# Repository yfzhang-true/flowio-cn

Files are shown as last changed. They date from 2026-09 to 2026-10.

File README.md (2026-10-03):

# FLOWIO-CN

**Open-source pneumatic soft robotics control platform** — from 4-layer PCB to digital twin.






## What is this?

FLOWIO-CN is a fully open-source, production-ready pneumatic soft robotics control platform. It's the Chinese domestic alternative to MIT's FlowIO, designed for B2B rehabilitation glove manufacturers (¥300-500/kit including board + firmware + SDK).

**One person, AI-driven, from zero to product in 3 days.**

## Architecture

```
┌─────────────────────────────────────────────────┐
│  Digital Twin (Web)                             │
│  3D exploded view · airflow/current viz        │
│  Real-time telemetry · simulation lab          │
├─────────────────────────────────────────────────┤
│  Python SDK · BLE GATT · Serial CLI            │
├─────────────────────────────────────────────────┤
│  ESP32-S3 Firmware (ESP-IDF + FreeRTOS)       │
│  pn_core (platform-independent C)              │
│  TCA9548A I2C mux · WS2812 · 8× valve PWM    │
├─────────────────────────────────────────────────┤
│  4-Layer PCB (90×75mm) · FreeCAD enclosure    │
│  JLC fab-ready · via-in-pad Type VII          │
└─────────────────────────────────────────────────┘
```

## Quick Start

### Digital Twin (no hardware needed)
```bash
cd firmware/twin
"E:/Program Files/KiCad/10.0/bin/python.exe" server.py
# Open http://localhost:8000
```

### Flash Firmware
```bash
cd firmware
idf.py flash monitor
```

### Python SDK
```python
from flowio_sdk import FlowIO
device = FlowIO("COM3")
device.inflate(port=1, pwm=180)
device.hold(port=1)
```

## Repository Structure

| Directory | Description |
|---|---|
| `firmware/` | ESP32-S3 firmware + digital twin + tests |
| `hardware/flowio-p1/` | KiCad PCB project + fab package |
| `sdk/python/` | flowio_sdk Python package |
| `book/` | LaTeX book source (94 pages, Chinese) |
| `docs/superpowers/` | Engineering specs & plans |
| `enclosure/` | FreeCAD parametric case |

## Key Metrics

| Metric | Value |
|---|---|
| PCB layers | 4 (F: signal · In1: GND · In2: power split · B: signal) |
| DRC violations | **0** (from 146 initial) |
| Host tests | 33/33 ✅ |
| Web app tests | 44/44 ✅ |
| API tests | 50/50 ✅ |
| BLE services | 4 (Command · Telemetry · Config · DeviceInfo) |
| Book | 94 pages · 14 chapters · 31 bib entries |

## Documentation

- [BRINGUP Guide](firmware/BRINGUP.md) — Hardware bring-up checklist
- [API v1.2](firmware/twin/API.md) — HTTP interface spec
- [BLE Interface](firmware/twin/BLE.md) — GATT service/characteristic spec
- [Book PDF](book/build/main.pdf) — 《气动软体机器人自研实战》(in progress)

## License

- **Code**: MIT License
- **Hardware (PCB/enclosure)**: CERN-OHL-S v2
- **Documentation/Book**: CC BY-NC-ND 4.0

## Author

**张越飞 (Zhang Yuefei)** — Embedded Software Engineer
- GitHub: [@yfzhang-true](https://github.com/yfzhang-true)
- Email: yuefeizzz@163.com

---

*Built with AI-driven development methodology. Every spec, plan, test, and commit is documented in `docs/superpowers/`.*

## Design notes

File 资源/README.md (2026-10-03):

# E:/FLOWIO/资源 — 分类清单（2026-10-03 整理后 627M→401M）

## 实物图/（59 图）
- handes_p1-p18: 汉戴斯 FlowIO 代工平替 PCB 实物 → 书稿 ch5 供应链
- valve0520d_*/0520f_*: 两种阀实拍 → ch2 阀选型对照
- mos_p1-p7 / sanjian_p1-p9 / xgzp_p3 / dmm / solder_check → ch5/ch13
- 1-4.png / BOM*.png: 其他采购截图

## 器件规格书/（7 项+2 目录）
- 电磁阀 0520D/F 中文规格书（P_min=-53.3kPa 来源）→ ch2 bib
- XGZP6897D V1.1 + 数据手册/（含 V2.5/ESP32-WROOM 中文/TCA TI 版）→ ch2/ch7 bib
- AO3400A/电感/DC005/XH/CH340N（数据手册/ 目录）→ ch3 bib

## 官方参考/（17 项 + official-3mf/22 模型）
- FlowIO CHI'21 论文 PDF + Arduino 库 7 源文件 + mp4 + gui.html（对标素材，版权纪律：只引签名不摘码）
- official-3mf/: S/M/L/Main 模块结构件 → ch6 尺寸对照表

## 开发板资料/（4 项）
- DevKitC-1 原理图 PDF + N16R8 资料目录 + Arduino API 文档 + AeonLabs 工程 → ch3 对照

## 已删（226M）
- FLOWIO-外部参考（嵌套残留）/ extracted/(116M) / kicad/(32M) / kicad zip(53M) / TCA rar(25M)

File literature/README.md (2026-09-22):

# 文献库总台账

> 命名规范：`YYYY-一作姓[-venue]-slug.pdf`（经内容验证后统一重命名，2026-09-22）
> 结构：根目录 = 15 篇精读核心；`citers/` = 81 篇 FlowIO 被引（S2 元数据对账）
> 全部 PDF 配同名 `.txt` 提取文本（图片扫描件除外）；原始数据 `s2_*.json`

## 一、核心文献（根目录，14 篇，全部深读）

### 平台与物理（FlowIO 复刻主线）

| 文件 | 文献 | 价值 |
|---|---|---|
| `2021-shtarbanov-chi-ea-flowio.pdf` | FlowIO 平台（CHI'21 EA，被引 101） | 对标本体：7 常闭阀架构、单传感器分时、±179/+207kPa 包线、泵 PWM 调流 |
| `2025-shtarbanov-phd-thesis.pdf` | Shtarbanov 博士论文（303 页） | **Table 2/3 泵实测锚点**（Small -38~+61kPa/±0.3L/min）、5 配置、12 部署案例、模块生态 |
| `2022-xavier-frontiers-nonlinear-controllers.pdf` | Xavier 控制器论文（Front. Robot. AI） | 物理模型权威：dP/dt=γP/V·Q + ANSI 阀孔方程 + choked、γ=1.2 |
| `2020-xavier-aim-pneumatic-sources.pdf` | Xavier 泵源建模（IEEE/ASME AIM 2020） | 正排量泵=理想流量源；储气罐平滑；FCB 综述 |
| `2020-stanley-asme-lumped-param-circuits.pdf` | Stanley & Amini RC 时序（ASME） | 次要损失阻力 ΔP=½Kρu²；RC 动力学；验证区 0.5–16mL 互洽 |
| `2013-yao-uist-pneui.pdf` | PneUI（UIST'13，被引 201-1000） | 界面设计参考：压力→形变连续映射、各向异性材料 |
| `2021-afsar-uist-omnifiber.pdf` | OmniFiber（UIST'21） | 流体纤维驱动、绕线交互（Shtarbanov 合作） |
| `2022-youn-tei-pneubots.pdf` | PneuBots（TEI'22） | 模块化充气教育套件——P0 教育定位直接对标 |
| `2022-aljomairi-smarchs-thesis-pneuknit.pdf` | PneuKnit（MIT SMArchS 2022） | 气压针织自成形（建筑/可穿戴） |

### 精细动作控制（2026-09-22 新增，笔记 19/20/21）

| 文件 | 文献 | 价值 |
|---|---|---|
| `2026-chen-arxiv-cnc-ergonomic-glove.pdf` | Chen 2026（arXiv 2604.00768，Sant'Anna） | **架构同构验证**：ESP32 WiFi+浏览器 GUI+12 电磁阀+双作用+CNC 热封（FDM 改装）+90g；患者 50-70kPa |
| `2026-xie-advsci-portable-thumb-glove.pdf` | Xie 2026（Advanced Science，CUHK 汤启宇组，CC-BY，DOI 10.1002/advs.76275） | **拇指精细答案**：双腔折纸差压（143°）、18N、XGZP6857A 传感器（同我们 BOM）、IMU 测角、贝叶斯 AAN 控制 |
| `2026-yilmaz-amt-fabric-gloves-review.pdf` | Yilmaz 2026 综述（Adv. Mater. Technol.，CC-BY，DOI 10.1002/admt.202502282） | **行业地图**：5 大制造家族；"开环对康复手套根本不够"；行业无统一测试标准=评估卖点机会 |
| `2026-xu-uppsala-pneumatic-circuits-thesis.pdf` | Xu 2026 博士论文（Uppsala） | 无电子气动逻辑+多路复用（技术雷达）；RC 类比验证一阶充放气建模 |
| `2022-wang-appsci-thumb-assist-comparison.pdf` | Wang 2022（Applied Sciences 12:3735，千叶大学，CC-BY） | **拇指通道裁决**：3C-ACT 三腔独立 Kapandji 满分 vs M-ACT 模块化耦合 0-5；最优组合=3C 拇指+模块四指；"控制方法待开发"=B2B 定位原文 |
| `2018-cn108392375a-patent-pneumatic-glove.pdf` | 专利 CN108392375A（郑州大学） | 免费竞品拆机（图片扫描件，无 txt；全文拆解见笔记 20）：双泵/双作用/12 传感/迭代学习 |
| `2022-sansone-actuators-sma-torsion.pdf` | Sansone 2022（Actuators 11:81） | ⚠️ 误下载（想要 3C-ACT 拇指论文，此为 SMA 扭转执行器）；留档，与产品无关 |

## 二、被引文献（citers/，81 篇）

- 完整索引（标题/一作/venue/被引/本地文件）：**[citers/INDEX.md](citers/INDEX.md)**
- 阅读笔记（分层：深读/扫读）：**[citers/READING-NOTES.md](citers/READING-NOTES.md)**
- 学术地图与客户清单：**[../study-notes/14-学术地图与潜在客户.md](../study-notes/14-学术地图与潜在客户.md)**

## 三、检索与整理方法存档

- AMiner：精确标题走 `search_paper_by_title`（keyword-only 常返回 no data）；被引清单用 S2 API；机构信息 `get_paper_detail`
- DOI 勘误：Xavier 2022 = 10.3389/frobt.2022.**818187**；FlowIO 系 CHI'21 EA；Yilmaz 综述 = **10.1002/admt.202502282**（Advanced Materials Technologies，非 Advanced Science）；Wang 拇指对比 = **10.3390/app12083735**（Applied Sciences 12(8):3735，非 Actuators）
- 下载坑：远端静默截断（无 %%EOF）需续传重下；ACM/Wiley/MDPI 反爬交用户浏览器（Cloudflare 拦 curl/WebFetch）；Google Patents PDF 是图片扫描件（无 txt，内容走网页版）
- 验证流程（2026-09-22 定型）：pypdf 页数+首页文本 → 标题/作者/DOI 比对清单 → 统一命名 `YYYY-一作姓-venue-slug` → 全文 .txt 提取（errors='replace'）→ 误下载留档并注明
- 本机 Python：`D:\MiniConda\python.exe`（PATH 里 `WindowsApps/python` 是商店占位符 exit 49，`/d/miniconda3` 不存在）
- 重命名流程：pypdf 提取首页 → 归一化标题前缀匹配 S2 元数据（75/82 自动）→ DOI/人工补 6 篇 → 重复件（Xavier controllers citers 副本）删除

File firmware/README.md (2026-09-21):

# FlowIO 兼容 P0 固件（ESP32-S3）

对标 FlowIO 功能的自主实现固件（100% 原创代码，逻辑依据 study-notes/02 功能性笔记）。

## 目录结构

```
components/
  pn_core/       纯逻辑层（动作/闭环/协议）——不依赖任何平台，主机可测
  pn_hal_esp32/  ESP32-S3 硬件层（LEDC 阀/泵 + RMT 舵机 + I2C 传感器）
main/            app_main：10ms 控制任务 + 串口 CLI
tests/           主机单元测试（gcc/cmake/ninja，无需 ESP-IDF）
```

## 分层架构

```
应用层   main.c（CLI + 10ms 控制任务）
协议层   proto.c  [0xA5][cmd][ports][pwm][crc8]
动作层   actions.c / closedloop.c（端口三胞胎/方向阀/泵/状态字/节能/超压保护/压力闭环）
HAL      hal_if.h 契约 ← pn_hal_esp32 实现（目标机）/ mock_hal（测试）
```

## 主机单元测试（改逻辑必跑）

```bash
cd tests
cmake -B build-test -G Ninja -DCMAKE_BUILD_TYPE=Debug
cmake --build build-test
./build-test/pn_tests.exe        # 21 tests 全绿 = 逻辑层可信
```

## 目标机构建/烧录（需 ESP-IDF v5.5.5 @ E:\Espressif）

```bash
./idf_build.sh build     # 编译（生成 build/flowio_p0.bin，目标 esp32s3）
./idf_build.sh flash     # 烧录（接开发板 USB 口）
./idf_build.sh monitor   # 串口监视器（Ctrl+] 退出）
```

## 串口 CLI（115200）

| 命令 | 功能 | 示例 |
| --- | --- | --- |
| `I <ports> <pwm>` | 充气 | `I 1 255` |
| `V <ports> <pwm>` | 抽气 | `V 1 200` |
| `R <ports>` | 释放 | `R 1` |
| `S <ports>` | 停止/保压 | `S 1` |
| `O <ports>` / `C <ports>` | 开/关端口阀 | `O 7` |
| `P` | 读传感器（kPa） | |
| `T` | 打印状态字 | |
| `L` | 阀保持节能 | |

## 状态字位定义

bit0-4=端口1-5 开、bit5=进气阀、bit6=排气阀、bit7=泵、bit9=传感器在线、bit15=错误。
协议层预留设备 ID 字段位（多设备同步，对标 FlowIO JS API 多机协同）。

## 安全设计

- 上电默认全关（常闭阀 + duty=0）；
- 超压保护为**硬规则**（pn_check_overpressure），任何上层不可关闭；
- TinyML/智能层永远是并行观察者，不进控制路径（study-notes/11）。

## 虚拟设备（无硬件调试）

逻辑层 + mock HAL 跑在电脑上，命令与真机完全一致：

```bash
cd virtual
cmake -B build -G Ninja && cmake --build build
./build/pn_virtual.exe
```

虚拟专属命令：`M <传感器号> <kPa>`（模拟压力读数）、`W <ms>`（推进时钟）、`K`（手动闭环 tick）、`Q` 退出。
示例：`I 1 255` → `M 0 30` → `G 1 40 0` → `K`（RUNNING）→ `M 0 45` → `K`（DONE reached=45kPa）→ `S 1`。

## 型号说明书

E:\FLOWIO\资源\datasheets\：ESP32-S3-WROOM-1 中文数据手册、XGZP6897D V2.5、TCA9548A。
DevKitC-1 用户指南（在线）：https://docs.espressif.com/projects/esp-idf/zh_CN/latest/esp32s3/hw-reference/esp32s3/user-guide-devkitc-1.html

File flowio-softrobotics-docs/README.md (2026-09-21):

# FlowIO（软体机器人气动平台）本地文档

FlowIO = Ali Shtarbanov（MIT Media Lab）开发的软体机器人气动开发平台，
官方文档站 <https://www.softrobotics.io/>（Wix 站点，2026-09-19 抓取转换为 Markdown）。

| 本地文件 | 内容 |
| --- | --- |
| `introduction.md` | Introduction |
| `documentation.md` | Documentation Overview |
| `gui-overview.md` | GUI Overview |
| `gui.md` | Launch GUI |
| `auto-off.md` | Auto Power OFF |
| `battery-charging.md` | Battery Charging |
| `pneumatic-configurations.md` | Pneumatic Configurations |
| `external-air-supply.md` | External Air Supply |
| `latency-and-delays.md` | Latency & Delays |
| `more-than-5-ports.md` | More Than 5 Ports |
| `software-stack.md` | Software Stack |
| `arduino-api.md` | Arduino API |
| `premium-content.md` | Premium / IoT Features |
| `limitations.md` | Limitations |
| `about.md` | About |
| `chi22.md` | CHI'22 Paper Page |
| `dis23.md` | DIS'23 Paper Page |
| `fab24.md` | FAB24 Paper Page |

补充材料：
- `arduino-library-readmes/` — GitHub 上 FlowIO Arduino 库的 README（API 文档入口，固件等高层代码在私有仓库需申请）
- `images/` — 页面配图（含气动配置、GUI 截图等）
- 论文：`E:\FLOWIO\FlowIO Development Platform – the Pneumatic "Raspberry Pi"for Sof Robotics.pdf`（CHI 2021，与官网首页挂载的 PDF 为同一文件）
- Arduino 库源码：`E:\FLOWIO\FlowIO-Arduino-Libraries-master\`（github.com/shtarbanov/FlowIO-Arduino-Libraries，
  含 `FlowIO_Library_2026.03.23` 最新版库 + 236 个示例 `.ino` + 历史版本；另保留同名 .zip）
- free/pro 版库仓库（shtarbanov/FlowIO-Library-free-version- / -pro-version-）为空占位，需向作者申请私有固件仓库访问

未抓取（非文档内容）：商店/社区论坛/法律条款等页面。

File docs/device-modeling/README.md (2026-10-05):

# D4 视觉回归存证 — 孪生 3D 器件精确建模 + connections 驱动渲染 (2026-10-05)

> spec: docs/superpowers/specs/2026-10-05-device-modeling-connections-design.md §5/§7(验收 4)
> 截图: 本目录 `d4-*.png` (1680×1050, playwright 无头; 脚本 `firmware/twin/shots_d4.js`,
> 需 8017 孪生服务: `bash firmware/twin/run_tests.sh` 或手动起 `server.py`)。
> 重生成: `cd firmware/twin && node shots_d4.js [输出目录]` (默认落本目录)。

## 截图清单与判定点

| 截图 | 视角/态 | 判定点 (spec E1/E2 校正) |
|---|---|---|
| `d4-pump-top.png` | 泵模块装配位 + **隐壳透视** (截图工具临时 `pump_case.visible=false`, 非场景功能; 泵在封闭腔内, 唯一诚实观查法) | **顶置双嘴 ⌀4.2 垂直于泵轴** (E1: 旧版误建侧嘴); 泵头⌀24/电机⌀27 两段式; 硅胶支架环×2 抱头段/电机段; 电机端面红黑引线; 模块内跳管 (fit_pending 半透明) 自双嘴下行至面板快插 |
| `d4-valve-leads.png` | B 壁 (+Y) 正视塔层 | 11 阀 C 架本体 (devices3d 精确模型, 非盒近似); **红黑引线自阀 -Y 侧出体 → 拱越 (z43.5, 阀顶与歧管块底净空带) → 沿壳外壁下落 → 穿 B 壁 TERM 槽 → 2P 白壳插入 J10-J17** (E2: 旧版引线缺失); 白壳视觉件在插座位; 测压支路自歧管顶过天花过孔垂直下行 |
| `d4-tube-routing.png` | 全局 3/4 (装配态) | **connections.json 驱动管路** (16 管, D4-A 折线): 模块间干管×2 (面板快插→R 壁 S/V 孔), 壳内 S/V/F 竖落管, 通道管 V×N2→CH 过孔, 测压支路 (歧管测压嘴→越歧管顶→天花过孔→XGZP P1); 泵电缆 J23→R 壁槽→模块出线孔→电机端子 |
| `d4-explode-follow.png` | 爆炸 k=1 | 连接边**端点随部件跟随拉伸** (spec §5): 测压支路自歧管层拉至 pcb 层, 模块干管拉伸跨主/泵模块间隙 —— 分装式教学价值可视 |
| `d4-click-highlight.png` | 点击 J10 热点 (raycaster 真点击) | 三类连接**高亮分色** (电气琥珀, 其余压暗); 提示 chip (左下): 器件名 + 气动/电气/机械计数; 热点卡照常弹出 (webapp 组件契约不破, 现 55/55) |

## 与官方参考照/实物照对照

参考照在主仓库 (worktree 外, 绝对路径):

| 孪生截图 | 参照 | 对照结论 |
|---|---|---|
| d4-pump-top.png | `E:/FLOWIO/literature/ZR370-03PM.pdf` p2 图纸 (顶置 2-⌀4.2 出气/进气口标注) + `E:/FLOWIO/资源/实物图/1.png`-`4.png` (整机实物) | 嘴位/朝向/头-电机两段比例一致; 充(S)/吸(V) 固定不可反接 (图纸标注同) |
| d4-valve-leads.png | `E:/FLOWIO/literature/F0520D.pdf` p2 图纸 + 实物照 `E:/FLOWIO/literature/extract/散件/` (p0-p8, 红黑引线+2P 白壳) + `E:/FLOWIO/资源/实物图/电磁阀052/` | C 架比例 (20.5×15×13 + 翻边)、红黑并排引线、白壳插接方向一致; F0520B/VV 总长 28+⌀4.6 顶嘴承插悬置态 (图纸直推) |
| d4-tube-routing.png | `E:/FLOWIO/资源/官方参考/flowio-official-gui-reference.png` (官方 GUI 整机) + `docs/pneumatic-diagram.md` §1-§5 (图谱拓扑真值) | 管路拓扑按 connections.json (机器真值) 而非目测; 官方为集成式单壳, 本机为分装双模块 (1h 决策), 干管跨接为设计意图非偏差 |
| d4-click-highlight.png | — (交互新增, 无官方对应) | spec §5 "点击器件→高亮其三类连接" 落地存证 |

## 已知视觉限制 (诚实记录, 非缺陷遮掩)

1. **引线/管与结构件的过越穿模**: 壳盖 (case_top) 无阀 N2 过孔/引线过孔 (盖开孔属
   enclosure 域待 1a 支架定型), 渲染折线穿过盖板处阅读为"过孔"; VS/VF 竖落管与
   J20/J22 插座体量轻微交叠 (真实走线在插座旁, 折线未让位)。
2. **tube.bend=2 为采购下料名义值**, 渲染折线按最小几何弯折 (2~4 点, 壁孔过越/障碍
   让位必须) —— 段长和仍可核算下料 (D4-A), 逐边路径见
   `firmware/twin/webapp/connections_scene.json` (flowio/twin/connections_render 生成)。
3. **引线桩深** = D2-A "诚实的不精确" (~60mm 视觉桩语义, 端点接真值插座位);
   精确线长/壳内走线属机械冻结后阶段 (spec §8 D2)。
4. V2-V8 N2→CH 的 **x 向让位折线** 按 connections.json 字面映射渲染 (V2→CH2@29.5 等
   与阀列 x 不对齐处出现横行段) —— 配对疑点已核闭 (原 D4 报告"数据发现"收编于此):
   交织序下 V5.N2 (后行阀列 x=20) 映射 CH5@x=58, 渲染横行段横跨 38mm 为最长者;
   与 `connections.json _meta.conventions.vi_ch_pairing` 约定自洽 —— Vi→CH{i} 恒等
   配对是图谱拓扑约定, CH 孔-阀前后行的物理对号未钉真值 (case_geom CH_PORT_X 每列
   2 孔对应该列前/后行阀), 四条校验不受配对影响; BRINGUP §C 接管时对号, 本疑点关闭。

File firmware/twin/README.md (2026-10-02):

# twin/ — FlowIO-CN 数字孪生 + Web 控制台

启动：

```bash
"E:/Program Files/KiCad/10.0/bin/python.exe" server.py   # KPY（KiCad 自带 Python）
# → http://127.0.0.1:8000/
```

P1 板级说明：本目录含 P1 板级电气孪生（board_model）/参数化仿真（sim_engine）/3D 装配（meshes），
协议契约见 `API.md`（v1.2）与 `BLE.md`（真机 Web-Bluetooth 模式）；回板校准动线见 `firmware/BRINGUP.md`。

## 前端 v2（webapp/，2026-10-02 交付）

`/` = v2 产品爆炸视图核心（零构建 ES Modules，`webapp/` 直服）：

- **全屏 3D 产品场景**为唯一主角：装配叙事（加载 1.5s 部件散位收敛）+ 运输条爆炸滑杆（0-100%），
  材质对标 Liquid Glass（壳喷砂灰 / PCB 墨绿微金属 / 器件中性灰 + 环境反射）。
- **气流粒子与电流辉光长在产品上**：流拓扑由 `hardware/flowio-p1/enclosure/make_flows.py`
  从 pos.csv 同源生成 `webapp/flows.json`/`hotspots.json`；电流=行进虚线（阀电流驱动 uGain/uSpeed），
  气流=端口 Bezier 粒子流（duty 驱动速度，真空=琥珀色反向）。
- **仪表盘降级为辅助**：左控制抽屉（阀/泵 Apple 分段控件 → CLI）/ 右遥测抽屉（5 张 sparkline 玻璃卡，
  点卡展开 ECharts）/ 器件热点卡（点击 3D 器件）/ 仿真实验室全屏浮层 / 状态行（stale 红点/未标定黄徽）。
- `?debug` 叠 fps/粒子/延迟浮层；真机模式=顶栏「连接真机」（Web Bluetooth，0xA5 帧，`ble.js`）。
- 调试钩：`window.__t2 = {scene, flows, panels, simlab}`（test_webapp.js 全链断言经此读取渲染态）。
- 旧版 gui.html 挂 `/classic` 过渡（`/gui` 301→`/`）；API v1.2 端点零改动。

截图（`shots/v2_*.png`）：`v2_01_intro` 首屏装配 · `v2_02_explode50` 爆炸 50% ·
`v2_03_inflate`/`v2_04_silent` 充气/静默差分 · `v2_05_vacuum` 真空琥珀反向 ·
`v2_06_hotspot` U3 热点卡 · `v2_07_telemetry` 遥测抽屉 · `v2_08_simlab` 仿真浮层 ·
`v2_09_stale` 断连态 · `v2_10_recovered` 恢复态。

测试：`node test_webapp.js`（v2 全链 44 断言，需 8017 实例）+ 旧三套（test_gui/test_gui_p1/test_e2e 已挂 /classic）。

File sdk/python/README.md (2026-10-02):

# flowio_sdk — FLOWIO-CN 上位机 Python SDK

0xA5 二进制帧协议的 Python 实现，编解码与固件 `firmware/components/pn_core/src/proto.c` **同向量**（测试向量共享，见 `tests/vectors.json`）。

```bash
pip install pyserial                      # 可选依赖（仅串口传输需要；SDK 本体 stdlib-only）
python examples/hello_glove.py COM3       # 充→保→释→抽 一个来回
```

```python
from flowio_sdk import FlowIO
io = FlowIO("COM3")          # 或 FlowIO(transport=自备对象) 离线测试
io.inflate(1, 180)           # '+' 端口1 充气 180/255
io.hold(1); io.release(1)    # '!' 保压 / '^' 释放
print(io.state())            # 'S' 读状态字（str）
```

协议真源与帧格式：`firmware/components/pn_core/include/pn_core/proto.h` —— 5 字节帧 `[0xA5][cmd][ports][pwm][crc8]`，cmd 为 ASCII 动作码（`! + - ^ o c ? S R`），ports 为 bit0..4 端口掩码，CRC-8 poly=0x07 init=0x00 覆盖前 4 字节。

测试：`python tests/test_protocol.py`（8 组固件同向量双向校验，通过输出 `sdk protocol tests OK`）。

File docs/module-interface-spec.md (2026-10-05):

# FLOWIO-CN 模块接口规约（Module Interface Spec · device-modeling D3）

> **机器真值源**：`hardware/flowio-p1/enclosure/connections.json`（modules 块 + 三类边——面名/
> 计数/口径/管长/边数全部摘自它）· `hardware/flowio-p1/enclosure/devices.json`
> `pneumatic_devices.*.geom3d`（端点级位/向/径细节）。
> 本文档是连接图谱的**人读投影**：数据分歧以 connections.json 为准；守卫测试
> `flowio/tests/test_module_interface_spec.py` 把本文硬编码数字钉在真值上（漂移必红）。
> 上游：spec `docs/superpowers/specs/2026-10-05-device-modeling-connections-design.md` §1/§4 ·
> 气路真值 `docs/pneumatic-diagram.md` §3 · 装配执行 `docs/bringup-checklist.md`。
> 生成日期：2026-10-05（D3）。架构：1f-β 公共歧管 + 1h 分装式双模块，全 NC 阀。

## 1. 总则

1. **接口先于几何**：每器件 = 三接口面（气动/电气/机械）+ 参数化几何；几何服务于接口。
2. **模块 = 器件 + 内部边组合**：主模块 = 主板/歧管/11 阀/壳内管路的组合，泵模块 = 泵 +
   面板快插 + 底座 + 跳管的组合；内部边两端点均在本模块内，不承担模块间契约。
3. **对外接口面 = 模块间边的端点**：模块间恰 3 条边（2 气管 + 1 电缆），其端点即两模块的
   全部对外契约；其余面对内（壳内免维护）。
4. **一致性声明**：本文所有面名/口径/长度/边数可溯源到 connections.json（modules 块与三类
   边）与 devices.json geom3d；手改真值后本文由守卫测试逼同步，**禁止在文档发明第二套接口数据**。

### 1.1 模块总览（数据来源：connections.json modules 块）

| 模块 | 功能 | 面（气动/电气/机械） | 面合计 | 对外面 | 物理形态 |
|---|---|---|---|---|---|
| Main | 控制与分配 | 12 / 12 / 4 | 28 | 12 | 主壳（R 壁 S/V/F 孔带 z=5.0 + B 壁 CH×8 @z=17.25） |
| PMod | 气源 | 2 / 1 / 1 | 4 | 4 | 独立小盒 66.9×32.8×41.3，主壳 +X 侧间距 30，桌面放置 |
| ATM | 大气环境节点（非实体） | 1 / 0 / 0 | 1 | 1 | 排气终端与传感表压基准的显式接地 |

边计数合计：气动 29 / 电气 14 / 机械 15（`flowio.twin.connections` 校验锚点，与
`test_connections.py` N_PNEU/N_ELEC/N_MECH 同源钉死；模块间边恰 3 条见 §4）。

### 1.2 对外接口面清单（数据来源：connections.json modules 块 external=true 面）

| 面地址 | 类 | 口径 | 用途/位置 |
|---|----|---|---|
| Main.S_wall | 气动 | ⌀5.6 | 充干管接入（R 壁 @y20.4 z5.0；S=充不可对调） |
| Main.V_wall | 气动 | ⌀5.6 | 吸干管接入（R 壁 @y31.4 z5.0） |
| Main.F_wall | 气动 | ⌀4.8 | 排气→大气（R 壁 @y42.4 z5.0，可塞消音棉，无密封要求） |
| Main.CH1 | 气动 | ⌀3.4 | 通道管→cuff（B 壁 @x20.0 z17.25） |
| Main.CH2 | 气动 | ⌀3.4 | 同上（@x29.5） |
| Main.CH3 | 气动 | ⌀3.4 | 同上（@x39.0） |
| Main.CH4 | 气动 | ⌀3.4 | 同上（@x48.5） |
| Main.CH5 | 气动 | ⌀3.4 | 同上（@x58.0） |
| Main.CH6 | 气动 | ⌀3.4 | 同上（@x67.5） |
| Main.CH7 | 气动 | ⌀3.4 | 同上（@x77.0） |
| Main.CH8 | 气动 | ⌀3.4 | 同上（@x86.5） |
| Main.J23 | 电气 | XH2.54-2P（C7429671） | 泵电机座（Q16；穿壁电缆→泵模块） |
| PMod.S_panel | 气动 | ⌀5.6 | 面板充气快插（泵出口侧） |
| PMod.V_panel | 气动 | ⌀5.6 | 面板吸气快插（泵入口侧） |
| PMod.cable_2p | 电气 | 2P 插头（出线孔 ⌀5.0） | 电机插头←主模块 J23 电缆 |
| PMod.base | 机械 | — | 自足式底座（桌面放置，无壳间紧固） |
| ATM.open | 气动 | — | 大气（表压 0 基准；F 排气与 XGZP P2 的接地目标） |

## 2. 主模块 Main（控制与分配）

**功能**：接收 USB-C 5V 单电源，驱动 11 路 NC 电磁阀（V1-V8 通道阀 + VS 充/VV 吸/VF 排三
主阀）构成 1f-β 公共歧管，把泵模块送来的气压分配/回收至 8 通道 cuff；板载 XGZP6897D 实时
测压闭环（>±35kPa 工作带、M>+35 停泵 `0x02`、M<−40 真空钳位 `0x04`，diagram §1）。壳内
气路/阀线免维护——模块间契约仅 §4 的 2 管 1 缆。

### 2.1 三接口面表（数据来源：connections.json modules 块 Main 条目）

| 面 | 对内 | 对外 |
|----|---|---|
| 气动（12 面） | M 公共歧管腔脊 ⌀4.0（内部枢纽：11 阀嘴承插 + 测压支路接入；内流道 ⌀3.2） | 11 壁面孔：S_wall/V_wall ⌀5.6（→泵模块）、F_wall ⌀4.8（→大气）、CH1-CH8 ⌀3.4（→cuff）。引压口无独立面，由 M→S1.P1 边承载（歧管测压嘴 ⌀4.4×伸出 5，右面 x=105） |
| 电气（12 面） | J10-J17（8 通道阀座）+ J20（VS）+ J21（VV）+ J22（VF）共 11 座 XH2.54-2P，板载阀驱动 | J23 泵电机座（XH2.54-2P，Q16 驱动）→穿壁电缆→泵模块。USB-C 电源输入（J1）属板级/网表域，不入图谱（conventions.elec_scope） |
| 机械（4 面） | valve_bracket 阀印刷支架 / manifold_seat 歧管 4 支腿 M3 座 / case_cover 壳盖承面 / pcb 主板板面 | —（壁面快插/出线孔按真值归气动/电气面；壳间无紧固） |

### 2.2 对内构成（数据来源：connections.json 三类边涉及 Main 端点条目统计）

| 域 | 边数 | 构成 |
|----|---|---|
| 气动 | 24 | 11 承插（V1-V8/VS/VF 嘴 ⌀3.0→承口 ⌀3.2；VV 嘴 ⌀4.6→承口 ⌀4.8+变径腔 z50 锥收，插入 ~5.5mm）+ 3 壳内主阀/排气管（S_wall→VS.N2、V_wall→VV.N2 各 ID5→ID3 200mm；VF.N2→F_wall ID3 200mm）+ 8 通道管（Vi.N2→CHi，ID3×OD7 175mm）+ 测压支路 M→S1.P1（ID3×OD7 500mm 死端引压）+ F_wall→ATM 排气终端 |
| 电气 | 11 | 阀引线 2P 白壳→XH 座（V1-V8→J10-J17、VS/VV/VF→J20/J21/J22），桩深 60mm（D2-A 视觉桩） |
| 机械 | 13 | 10×D 阀 C 架顶翻边固定（V1-V8/VS/VF）+ 1×VV B 阀 ⌀2.0 孔×2 螺固 + 1×XGZP SOIC8 板载回流焊 + 1×歧管 4 支腿 M3 立于壳盖 |

## 3. 泵模块 PMod（气源）

**功能**：自足式气源小盒——ZR370-03PM 泵（头 ⌀24×27.3 + 电机 ⌀27×30.8，总长 58.1 横躺，
**顶置双嘴 ⌀4.2×7.5 垂直于轴线**）+ 面板双快插 + 底座硅胶支架减振；哑器件，电机 2 线回主
模块 J23（Q16），占空比 ≤95% 调速，充/吸口由泵结构固定（电机反接不换向）。

### 3.1 三接口面表（数据来源：connections.json modules 块 PMod 条目）

| 面 | 对内 | 对外 |
|----|---|---|
| 气动（2 面） | 泵双嘴 CHG（充）/SUCK（吸）⌀4.2 → ID5 跳管 → 面板快插 | S_panel/V_panel ⌀5.6（→主模块 S/V 壁孔，干管 ×2） |
| 电气（1 面） | cable_2p → 泵电机端子 MOTOR_POS/MOTOR_NEG（端面焊片，图纸标注正/负极） | 2P 插头（面板出线孔 ⌀5.0 引出）←主模块 J23 穿壁电缆 |
| 机械（1 面） | base 底座 + 硅胶支架环 ×2（环 ID23/OD26 抱 ⌀24 头段/⌀27 电机段，脚距 46mm M3） | —（自足式桌面放置，无壳间紧固） |

### 3.2 对内构成（数据来源：connections.json 三类边涉及 PMod 端点条目统计）

| 域 | 边数 | 构成 |
|----|---|---|
| 气动 | 2 | 跳管 ×2（P1.CHG→S_panel、P1.SUCK→V_panel，ID5×OD7 150mm 弯 2；模块内走管避免折弯 <R15）——⚠ fit_pending ×2（见 §6） |
| 电气 | 2 | 电机引线 ×2（cable_2p→MOTOR_POS/NEG；长度待装配态实测，D2-A 桩深） |
| 机械 | 2 | 支架环 #0/#1 过盈夹持于底座（silicone_clamp，脚距 46mm M3 ×2 前后） |

## 4. 模块间连接（恰 3 条边）

数据来源：connections.json 三类边中跨模块边全量（机器可校验：多一条/少一条守卫测试翻红）。

| # | 边 | 类 | 规格 | 端点细节 |
|---|----|----|---|---|
| 1 | 充干管 PMod.S_panel→Main.S_wall | tube | ID5×OD7，350mm，弯 2 | 两端快插/壁孔均 ⌀5.6 |
| 2 | 吸干管 PMod.V_panel→Main.V_wall | tube | ID5×OD7，350mm，弯 2 | 同上 |
| 3 | 电机电缆 Main.J23→PMod.cable_2p | cable_2p | 150mm，XH2.54-2P（C7429671） | 主壳穿壁出线孔→泵模块面板出线孔 ⌀5.0 |

> ⚠ **S=充（泵出口）/V=吸（泵入口），不可对调**——充/吸口由泵结构固定（diagram §3 row2；
> 机器化判据 = `test_connections.py` R3 S/V 对调翻红）。极性错误（正负反接）≠ 换向，但
> 泵可能不转/异响：泵端焊片图纸标注正/负极，接线以标注为准。干管跨 30mm 模块间隙，
> 350mm 为折线下料长（0.3~0.4m 取中值，含弯曲余量）。

## 5. 装配检查项（模块间 3 边显式）

### 5.1 缺失后果矩阵与处置（后果判定依据 diagram §4 六动作阀态；六动作含搬气）

| 缺失边 | 充 | 吸 | 排 | 保 | 测 | 搬气 | 检查方法 | 恢复动作 |
|---|----|----|----|----|----|---|---|---|
| 充干管 | ✗ 无气源 | ○ 降级（泵出口开放大气，负压路仍通） | ○ | ○ | ○ | ✗（S 路断） | 目视两端插入快插/壁孔 + 手拉不脱（C3/C5 拉脱口径）；充单通道无压升即疑此管 | 重插→皂液复查（diagram §6 C3）；管口胀大/划伤按 §4 规格重下料（ID5×OD7 350mm） |
| 吸干管 | ○ 降级（泵入口开放大气，充压路仍通） | ✗ 无负压 | ○ | ○ | ○ | ✗（V 路断） | 同上；吸单通道抽不到负压即疑此管 | 同上（ID5×OD7 350mm） |
| 电机电缆 | ✗ 泵不转 | ✗ 泵不转 | ○ | ○ | ○ | ✗ | 目视 J23 与 2P 插头插合到位；**断电**静态 A5 跨测 J23 两脚绕组（数 Ω）；bringup §C PUMP 行听泵转声/<0.5A | 重插 2P；端子损坏换 XH2.54-2P 插头重压接（对拍 BOM C7429671） |

三边同时缺失 = 主模块退化为"被动泄压 + 测压"半机（排/保/测仍可用）——任何一边缺失都
是**显式装配检查项**，不允通过功能自测侥幸掩盖。

### 5.2 装配顺序建议（对齐 diagram §5，模块间域）

1. **机械先行**：主壳内阀阵/歧管落座（diagram §5 step1-2）；泵模块放置到位——主壳 +X 侧
   间距 30mm，桌面自足无紧固，仅对位（快插/出线孔朝向主壳 R 壁）。
2. **气路次之**：泵模块内跳管 ×2（step5 前半）→ 模块间干管 ×2（**S 对 S、V 对 V**）→
   气密检查 diagram §6 C1-C7 通过后才进入电装。
3. **电最后**：J23↔2P 电缆与 11 只阀引线在气密通过后插接（diagram §5 step6 的"阀线
   (12 只)"为 11 阀线+1 泵 JST 的压缩表述，本节拆分计数），进
   bringup §C 逐路。

**试装风险点**：
- 泵嘴 ⌀4.2 × ID5 跳管：fit_pending（registry §6 "ID5×OD7 定案 + 到货试装 4/5 取一"）——
  ID4 备料，到货择优，勿强行扩口；
- VF 静止密封方向：满压歧管下 V:F 口侧压降待验证（diagram §6 C7 / bringup §D D7），
  异常对照问询单 0520D §8 答复评估换向；
- 干管弯 2 折线跨 30mm 间隙：避免折弯 <R15（折扁 = C5 判据）。

## 6. 待实测项清单（与 connections.json WARN 清单对齐；到货实测后由 BRINGUP 关闭）

| 项 | WARN 类 | 现状 | 关闭通道 |
|----|---|---|---|
| VV.N2 对端端口 | inferred | F0520B p2 图纸仅标 N1 ⌀4.6；N2 按家族对称惯例占位 ⌀3.0×3.0 | BRINGUP 卡尺实测校正（devices.json geom3d VV.N2 note） |
| VV.mount_hole 孔距 | inferred | ⌀2.0 孔×2，孔距 ±7.5 为占位值 | 商家答复（procurement H4 / 问询 1/3）→ 支架图纸 |
| 泵跳管口径 ×2 | fit_pending | 泵嘴 ⌀4.2 × ID5（id>嘴径，registry §6 定案待试装 4/5 取一） | 到货试装 → registry §6 / connections.json 定档 |
| VF 静止密封方向 | 图谱留档（conventions.n1_n2_semantics） | datasheet "正压接N2"为气流设计向，实际装配朝向相反；满压静止密封未验证，理论存在 M→VF 泄漏 | diagram §6 C7 / bringup §D D7 实测；问询单 0520D §8 |

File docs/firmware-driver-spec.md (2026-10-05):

# FLOWIO-CN 固件驱动规格（冻结）

> **地位**：P1.1 固件实现传感采集 / 阀泵 PWM 驱动 / 安全互锁的**唯一规格源**（T7 冻结，2026-10-03）。
> **参数单源纪律**：器件电气参数一律以 `hardware/flowio-p1/enclosure/devices.json` `pneumatic_devices` 段为准
> （T1 入库真值，改库即改孪生仿真——见 `firmware/twin/electrical_sim.py` 与其 5 断言测试）；本文只冻结
> **算法流程与策略参数**，不抄第二份器件参数。安全互锁阈值出自 spec §2.6 / `docs/component-registry.md` §5。
> 任何修改必须先改本文 + devices.json（或 spec §2.6），再改代码，再跑 `firmware/twin/run_tests.sh` 全链。

---

## 1. 压力传感驱动 — XGZP6897D 100KPDPN（非-C，定案）

BOM 为**非-C** 变体（`-C` 0x58 仅备选）。两者引脚兼容、**寄存器协议不同**——固件按下表实现，
不得混用 `-C` 的 0x04 连读流程（历史事故：PHYSICS-SPEC.md 曾按 -C 修正过一轮，本表为准）。

| 项 | 值 |
|---|---|
| I2C 地址 | **0x6D**（7bit，不可定制） |
| 总线 | ≤400kHz，SDA/SCL 上拉 4.7kΩ，VDD-GND 就近 0.1µF |
| 引脚 | 2=VDD / 6=SDA / 7=SCL / 8=GND；**1/3/4/5 = N/C 禁止连接** |
| 电源 | 2.5~5.5V（本机 3.3V 轨），待机 100nA，ESD 4kV，过载 2× |
| 量程/精度 | -100~100kPa 表压（DPN），±2%Span，24bit，响应 2.5ms，上电 24ms |
| 气路 | P1=高压端接管（⌀3.22 倒钩，3mm 管过盈），P2=低压端大气开放（表压读法） |

### 1.1 采集时序（寄存器流程）

```
上电 → 延时 ≥24ms（上电启动窗）
循环（50ms 控制节拍内）：
  1. 写 0x30 ← 0x0A            # CMD: 组合采集（压力+温度一次触发）
  2. 轮询 读 0x02 (Status)     # 等待 Sco（忙标志）清零——响应 2.5ms@默认 OSR
  3. 读 0x06/0x07/0x08         # 压力 24bit（MSB/MID/LSB，有符号补码和）
  4. 读 0x09/0x0A              # 温度 16bit
换算：
  P [count] = ((0x06<<16)+(0x07<<8)+0x08) 补码
  P [kPa]   = P_count / k      # k 查表按量程 Span；本机型 Span=200（±100kPa）→ k=32
  T [℃]    = T_raw / 256
诊断：0x01 PartID 上电读一次校验在位；NACK/PartID 错 → 置 PN_SW_ERROR，闭环动作禁启
```

- k 表（按 Span 档）：Span200（±100kPa 型）→ **k=32**；其余档位到货前不引入（单 SKU 纪律）。
- 量程饱和：|P| > 100kPa 的物理输入按传感器行为钳位 ±100（孪生 `SENSOR_SPAN_KPA` 同构）。
- 分时单传感（决策 3）：只测歧管 M 测量位；P2 的 8× 全通道方案留 P2，届时经 TCA9548A。

## 2. 阀/泵 PWM 驱动 — 保持参数表（drive_policy 冻结）

5.0V 轨 PWM 调制驱动 4.5V 额定执行器（判定方向=**防超压**，PWM 只向下调）。
器件真值：F0520D 450mA@4.5V（V1-V8 通道阀 + VS 充气主阀 + VF 排气主阀）、F0520B 300mA@4.5V（VV 真空主阀）、
ZR370-03PM 泵负载 500mA（电压窗全系 4.05~4.95V）。

### 2.1 阀三态驱动表（255 制 | 等效电压@5.0V 轨 | 稳态电流/阀）

| 状态 | 占空比 | 等效电压 | D 阀电流 | B 阀电流 | 时长/语义 |
|---|---|---|---|---|---|
| 吸入 pull-in | **100%** (255) | 5.00V | 0.50A | 0.33A | **≤100ms** 瞬态（+11% vs 额定，吸合最有利） |
| 全开保持 full-open | **90%** (230/255=90.2%) | 4.51V≈额定4.5V | 0.45A | 0.30A | 连续工作态（固件默认保持档） |
| 节能保持 economy | **55%** (140/255=54.9%) | 2.75V | 0.275A | 0.185A | **有意欠压**（保持力<吸合力，行业典型 40~60%）；35kPa 背压下限 BRINGUP 实测，不足升 65~70%；受限/错峰模式用 |
| 关断 | 0% (0) | 0V | 0 | 0 | 确定性关阀（S 语义；R 不清 duty） |

- 固件常量（`pn_core/types.h`）：`PN_HOLD_DEFAULT_DUTY=230`、`PN_HOLD_DEFAULT_DELAY_MS=100`（吸入窗）。
  节能档 55% 经 BLE Config 服务 `pwm_params` 下发，**不作默认**。
- 状态机（`pn_optimize_power`）：开阀 255 → 经 100ms 吸入窗 → 降保持档；关阀重开复位重来。

### 2.2 泵驱动

| 项 | 值 | 依据 |
|---|---|---|
| 占空比上限 | **≤95%** (242/255) | 5.0V 轨 > 4.95V 窗上限，1% 补偿 |
| 软启动互锁 | **≥1 通道阀开启才允许起泵**（0 通道开 → 泵强制 0） | 启动瞬态电流冲击覆盖 + 干泵防护（spec §2.6） |
| 寿命口径 | 3 万次循环（10s 开/5s 停） | 间歇工况与孪生 duty 模型同源 |
| 死头能力 | +120kPa / **-60kPa** | devices.json `pump.pressure_kpa`（孪生 `PUMP_P_MIN_KPA=-60`） |

## 3. 过压互锁（spec §2.6 硬约束）

量化依据：泵死头 +120/-60kPa >> 阀额定 ±45kPa——气路任一密闭段（泵开+通道全关）满压即超阀额定，
**保护只能靠固件闭环**，不靠死点自然限压。

| 参数 | 值 | 动作 |
|---|---|---|
| 闭环工作带 | **±35kPa**（≤+35 / ≥-35，康复工作点 20~30kPa 落在阀额定内） | XGZP 实时监测歧管 M，越带先调泵 PWM |
| 停泵阈值（正压） | **M > +35kPa** → 泵占空比强制 0 + 告警 | 闭环调压不够快时的硬互锁 |
| 真空钳位 | **M < -40kPa** → 泵强制 0 + 告警（由 -50 收紧至 -40） | 阀负压域（F0520D 吸模式 -40kPa 待 BRINGUP 验证） |
| 告警码 | `0x01 OVERLOAD`（母线超限）/ `0x02 OVERPRESSURE`（M>+35）/ `0x04 VACUUM_CLAMP`（M<-40） | 与 `electrical_sim.ALARM_*` 一致；BLE 上报+状态字 bit15 |
| 母线限流 | 适配器档 **3.0A 初值**（BRINGUP 实测后可调 3A/4A/5A） | 超限=受限模式：错峰（并发全开保持≤4 通道）或降节能保持 |

- 闭环调压**强制非可选**：充/吸动作一律带目标压力（G 命令语义），开环仅允许诊断模式。
- P2 可选：50kPa 机械泄压阀作硬件保险冗余（不进 P1.1 BOM）。
- 已知设计盲区（记录在案）：`twin_api.c` 旧超压阈值 120kPa > 传感器量程 100kPa，真机永不触发；
  按本表改为 +35kPa 工作带停泵路径（固件安全层 `pn_check_overpressure` 参数按本表传）。

## 4. 电气场景矩阵（孪生仿真基线，spec §2.7.1）

由 `firmware/twin/electrical_sim.py` 从 devices.json 实时计算（改库即改表）；断言见
`test_electrical_sim.py`（run_tests.sh §2d）。模型：`V_eff = duty×5.0V`，`I = V_eff/R_coil`
（R_coil=4.5V/额定电流：D=10Ω/B=15Ω），90% 保持恰=额定 450mA（registry "等效4.5V=额定"）。

| # | 场景 | 母线电流 | 判定 | 告警 |
|---|---|---|---|---|
| 1 | 单通道充气（V1+S 保持+泵95%） | 1.375A | ✓ ≤3A | — |
| 2 | 单通道吸气（V1+V 保持+泵95%） | 1.225A | ✓ ≤3A | — |
| 3 | 单通道排气（V1+F 保持，泵停） | 0.900A | ✓ ≤3A | — |
| 4 | 单通道保压（V1 节能保持） | 0.275A | ✓ ≤3A | — |
| 5 | 充气吸入瞬态（V1+S 100%≤100ms+泵） | 1.475A | ✓ 瞬态 ≤3A | — |
| 6 | 典型 3 通道充气（V1-3+S 保持+泵95%） | 2.275A | ✓ ≤3A | — |
| 7 | **最坏 9 阀全开保持+泵95%** | **4.525A** | **✗ >3A 受限模式** | `OVERLOAD` + 错峰/节能建议 |
| 8 | 错峰对策：9 阀节能保持+泵95% | 2.950A | ✓ ≤3A | — |
| 9 | 搬气（S+V+V1 保持+泵95%） | 1.675A | ✓ ≤3A | — |
| 10 | 非法工况：0 通道开起泵 | 0.000A | ✓ 互锁拦截（泵强制 0） | —（interlock 标记） |
| 11 | 过压 M=+36kPa | 0.900A | ✓ 停泵路径生效 | `OVERPRESSURE` |
| 12 | 真空钳位 M=-41kPa | 0.750A | ✓ 停泵路径生效 | `VACUUM_CLAMP` |

数值口径说明：registry `power_budget.worst_full_hold_9v_plus_pump=4.55A`（9×450mA 满额+泵 0.5A）
与本表 4.525A（泵按 95% 占空比 0.475A）同式同源；任务书速算 9×0.45×0.9+0.475≈4.12A 为
占空比直折的保守下界——三者同判 ">3A"，断言方向是**检测并告警**（受限模式），不是回避物理事实。

## 5. 验收断言（TDD，run_tests.sh §2d 全绿）

1. **超限检测与告警**：正常场景全 ≤3.0A 且无告警；最坏场景必检出 + `OVERLOAD` + 可行建议
   （节能保持对策自身须 ≤3A）。
2. **稳态有效电压窗**：全开保持 ∈[4.05,4.95]V；节能保持有意欠压 → ≥2.5V 且标记 `hold_economy`；
   吸入瞬态允许 5.0V 但 ≤100ms。
3. **泵限制**：请求超限被钳 ≤95%；0 通道开启时泵必 0（软启动互锁）。
4. **过压路径**：M>+35kPa 停泵+告警；M<-40kPa 真空钳位停泵+告警。
5. **参数单源**：临时改 devices.json 阀电流（0.45→0.60A）→ 仿真输出随之变（4.525→5.875A），
   字节级复原后回原值。

## 6. 变更纪律

- 本文与 devices.json / spec §2.6 三者不一致时，**以最近一次定案的设计 spec 为准并当场对齐其余两处**；
- BRINGUP 实测（30V/10A 电源 5.0V/10A 模式）产出：最小可靠保持占空比、泵启动电流、
  D 阀负压 -40kPa 验证、XGZP 0x6D 读通——回填 registry 后本表 §2/§3 数值随之更新并重跑全链。

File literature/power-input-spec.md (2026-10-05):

# 电源输入口调研（P1.1 v3 · 2026-10-05）

> 触发：v3 单 5V/3A 电源树需输入口承载 ~2.1A 峰值。核查发现**现板 DC005 额定仅 500mA——v3 新增第 6 项必修缺陷**。

## 1. ⛔ 现板 J1：C431533（SHOU HAN DC005）不可承载执行器轨

JLC 属性（一手）：**Current Rating 500mA** / Voltage 12V / Body Height 10.9mm /
13.6×9.9mm / 内孔 ⌀2.0 外触 ⌀6.3 / Right Angle Plugin。
- 500mA < 2.1A 峰值（8×0520D 0.75A + 0520F 0.36A + 泵启动 1A）→ **必须换型**。
- 本地 PDF `资源/器件规格书/数据手册/C431533_…_WJ1966441.PDF` 为纯机械图，无电气额定文字——额定以 JLC 属性为准。
- 连带影响：J1 槽带高度 case_geom（现按 10.9+0.2 收 11.1）与新 footprint 同步重算（换 DC-044 反而**收窄到 7.4**）。

## 2. 替代候选（JLC 一手属性，2026-10-05 实查）

### 2a. DC-044A-A200（XUNPU，C720575）——若保留圆口
- **3A / 30V** / Body Height **7.2mm**（比现 DC005 矮 3.7mm → J1 槽带收窄）
- 11.7×9.93mm / 内孔 ⌀2.0 外触 ⌀5.9 / Right Angle Plugin / 18.6k 库存 / ¥1.91 / extended
- 手册：`C720575_DC044A-A200_XUNPU.pdf`（图纸型，LCSC wmsc 直链）
- 适配器侧：5V/3A DC 圆头（5.5×2.1）通用款易购。

### 2b. TYPE-C-31-M-12（HRO，C165948）——若走"仅 USB-C"（决策点 1d 倾向）
- **5A / 20V** / 16P / USB 2.0 SMD Right Angle / 7.35mm 长 / 10k 插拔 / 425k 库存 / ¥1.30 / extended
- 手册：`C165948_typec31m12_HRO.pdf`（图纸型）
- 5V/3A 取电无需 PD 触发芯片：CC1/CC2 各接 5.1kΩ Rd 下拉 → 标准 Type-C 源默认供 5V；
  3A 档需源支持（市面 5V/3A 手机头普遍满足）。加 ESD 阵列（如 TVS/ESD 双二极管）。
- 板上已有 J2 TYPE-C（调试串口）→ 电源口与调试口并存两个 C 口，丝印区分"POWER/DATA"。

## 3. 与 1d 决策的关系

| 1d 选项 | 器件 | 承载 | 备注 |
|---|---|---|---|
| A. DC 圆口 | C720575（3A） | 3A ✓ | 现壳 J1 槽位保留，槽带收窄 |
| B. 仅 USB-C | C165948（5A） | 5A ✓ | 省一个插座品种；手机充电头即用（散件.pdf 卖家同款建议） |
| C. 两者并存 | 两者都用 | — | 或门防倒灌需二极管（0.3V 损耗）或理想二极管 |

**推荐 B（仅 USB-C）**：5A 冗余最大、种类最少、与 2b 的"5V2~3A 手机充电头"生态一致；
调试 C 口已有，电源 C 口新增一只 C165948 即可。

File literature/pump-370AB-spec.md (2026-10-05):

# 370 微型气泵 A/B 细分调研（P1.1 · 2026-10-05）

> 任务来源：用户"注意有两种370细分型号，370-A或者370-B"+"必须找到所有新增器件的数据手册，获取准确一手信息"。

## 1. A/B 语义（网络多源交叉，非厂商一手）

| 型号 | 调校取向 | 典型应用 | 同族配阀 |
|---|---|---|---|
| **370-A** | 正压充气型 | 电子血压计（袖带充气） | 0520A |
| **370-B** | 负压抽气型（充吸两用） | 电动吸奶器（吸引+可充气） | 0520B |

- 两者为同尺寸（370 电机级 ⌀24mm）隔膜泵的两个出厂调校版本，选型看正压输出 vs 负压真空度。
- 370-B @ 威力兹（fspump.cn，2017 存档快照）：额定电压 DC6.0V（<500mA）/ DC12V（<280mA）/ DC24V（<100mA）。
- 通用常识校验：正压泵=排气口高于大气压，负压泵=进气口低于大气压；隔膜式存在充吸两用型。
- 来源：上海霍亚流体 hnx-pump.com 选型文、东莞宗旨电子 gdaim.com、佛山威力兹 fspump.cn（**站点已停摆**，阿里云 ipvisit_stop）、新为诚 wcjx.net。

## 2. 用户实泵（淘宝套装散件，一手测量 + 图片直读）

### 2.1 散件.pdf（图片型 → pypdf 抽内嵌图 9 页全读，存 extract/散件/）
- 泵名：**"370直流充吸两用真空泵"，不分正负极**——单泵双口：顶部充气口 + 侧/顶吸气口，
  充=排气口出气，吸=进气口吸气 → **一只泵即覆盖 FlowIO 正压+负压双语义，无需双泵**。
- 配套：0520F 型两位三通阀×2（充气阀+吸气阀，断电 1↔2 通/通电 1↔3 通——与已定案 0520F 一致）。
- PWM 电子开关：3V~5V 工作电压，最大 2A，直通输出。
- **卖家供电推荐："电源推荐用 5V2a~5V3a 手机充电头 或 电脑USB3.0"** → 与 v3 单 5V 电源树互证。
- 附 Arduino/ESP8266/ESP32 示例码（50Hz PWM 14bit 控三路开关）——仅套件玩法，与本项目固件无关。

### 2.2 泵实物图（O1CN01…cib.jpg，listing 参数图直读）
| 尺寸 | 值 |
|---|-----|
| 总长 | **58mm** |
| 泵头（白） | **⌀27.4mm × 27mm** |
| 电机（银，370 级） | **⌀24mm × 31mm + 3.7mm 端子区** |
| 气嘴 | **顶部双嘴，⌀3.6mm，外伸 8.8mm** |
| 极性 | 红色正极标识（此 listing 版有极性；套装版不分） |

- **注意**：⌀3.6 双嘴 ≠ FIT0801（⌀4.3 单嘴变体）→ `370-pump-FIT0801-spec.md` 只作同族参考，
  **几何真值以本图为准入库 devices.json（27.4×27.4×58，port 双嘴朝上 exit_z≈27+8.8）**。
- 4mm 硅胶管直插过盈密封对 ⌀3.6 嘴同样成立（ID4 > OD3.6，撑紧密封）。

## 3. 官方 A/B 数据手册：⛔ 受阻 → 求助用户（已授权）

- 厂商级一手参数表（@5V 额定点、真空度/正压 kPa、流量-压力曲线）公开网不可得：
  威力兹官网停机、淘宝反爬、hnx-pump 首页无直链。
- **不阻塞设计**：电气（5V 直供、启动~1A、PWM）与几何（58×⌀27.4 双嘴）已从一手图源锁定；
  A/B 型号只影响 BOM 下单名与孪生数值微调。
- **求助项**：请用户把套装 listing 标题/规格页中 370-A 或 370-B 的字样与参数表截图或口述。
  （散件.pdf 全文与泵图均无 A/B 字样——listing 页面才有。）

## 4. 设计结论（回写 spec v3）

> **2026-10-05b 更新**：用户从 electromaker 渠道取得 **FIT0801 官方 DFRobot PDF**——
> 本档案 §2 的套装泵与 FIT0801 同族同规格（-58kPa/2.2LPM/1.5~5V）。**P1.1 BOM 正式
> 采购件定为 FIT0801**（官方链路稳定，⌀4.3 双嘴→4mm 管与歧管计划一致；端口语义：
> 侧口=吸气、中口=出气，反接换向功能两口都接管路后用不到）。套装泵降为实物对照。
> 详见 `dfrobot-fit0801-dfr0866-eval.md`。

1. 决策点 1e 简化：**单只"370 直流充吸两用真空泵"即覆盖充/吸双向**（FlowIO 泵模块等价物），
   无需 A+B 双泵；BOM 按"充吸两用型"下单，A/B 商家命名到单前请卖家确认即可。
2. 驱动：Q14（AO3400A）+ SS14 飞轮 + PWM 调速；启动冲击 ~1A（FIT0801 同族档案）已计入 5V/3A 轨预算。
3. 有刷不宜连续运转 → 固件间歇策略（孪生已有 pump duty 模型，PUMP_P_MIN_KPA=-58 保守成立）。
4. 减振软垫舱 + 软管接歧管（T6）；双嘴 ⌀4.3（FIT0801）→ 4mm 管；阀侧 Φ3.2 → 3mm 管；歧管内变径。

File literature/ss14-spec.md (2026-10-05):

# SS14 飞轮/续流二极管 + 驱动管（P1.1 · 2026-10-05）

## SS14（MDD，C2480）——阀/泵线圈续流

- JLC 一手属性：**1A / 40V 反向 / Vf 550mV@1A / 浪涌 25A / Ir 300µA@40V / SMA(DO-214AC)**，
  基本库（装配费最低），115.7 万库存，¥0.14。
- 手册：`C2480_SS14_MDD.pdf`（3 页，文本层完好，Schottky Barrier Rectifier DO-214AC/SMA）。
- 用途：10 路执行通道各 1 只（8×0520D + 0520F + 370 泵），反向并联线圈两端。
- 校验：线圈电流最大 0520F 320mA < 1A ✓；反向 40V >> 5V 轨 ✓；泵路启动 1A 时二极管不导通主回路
  （仅续流瞬间）✓。onsemi 版 C83852（40A 浪涌）作为备选不必——续流无浪涌应力。

## AO3400A（Alpha & Omega）——Q1-Q14 全部低边开关

- 手册已在库：`资源/器件规格书/数据手册/AO3400A_datasheet.pdf`（用户供）。
- 要点：30V / 连续 5.7A / Vgs(th) 0.65~1.45V / 3.3V GPIO 直驱 RDS(on)≈28mΩ@4.5V /
  SOT-23 / 0520F 320mA 与泵启动 ~1A 均远低于额定。
- 泵路 Q14 栅极 PWM：ESP32-S3 ledc 25kHz（高于人耳音频），栅阻 100Ω + 下拉 100k。

## 已在库无须再找的（本轮核对）

| 器件 | 状态 |
|---|---|
| 0520D / 0520F | ✅ 用户供 PDF（资源/器件规格书/）+ valve-0520df-spec.md |
| XGZP6897D-C | ✅ V1.1 PDF（资源/器件规格书/ + literature/xgzp6897d-c-datasheet-v1.1.pdf） |
| TCA9548A | ✅ literature/tca9548a-datasheet-ti.pdf + cjmcu-9548 模块图（仅 8 传感方案需要） |
| WAFER-XH2.54-4PZZ | ✅ C5359632 规格书（数据手册/） |
| TPS54331 / ESP32-S3-WROOM-1 / CH340 | ✅ 数据手册/ 目录已备 |

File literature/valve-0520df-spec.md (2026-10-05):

# 百乘电磁阀 0520D / 0520F 规格书摘要（惠州百乘电子）

> 来源：`E:\FLOWIO\资源\电磁阀0520D规格书4.5V.pdf`、`电磁阀0520F两位三通4.5V规格书.pdf`（各 3 页）
> 归档日期：2026-09-23 · 渲染页 `资源/valve0520d_p*.png`、`资源/valve0520f_p*.png`
> 用途：0520D=端口常闭阀（P0 装 3+1 备）；0520F=两位三通（排气/泄压实验 ×1）

## 1. 参数对照表

| 项 | 0520D（两位两通） | 0520F（两位三通） | 对本项目影响 |
|---|---|---|---|
| 额定电压 | DC 4.5V | DC 4.5V | 5V 母线直供（电流约 +11%，规格内） |
| 额定电流/功率 | **85mA ±10% / 0.38W**（自洽 4.5×0.085=0.38 ✓） | **320mA ±10% / 1.44W**，线圈 14.1Ω（三重自洽 ✓） | 4×D+F 全通 ≈ 0.7A（5V 下），MOS 10A/路裕量 30 倍+ |
| 动作压力范围 | **-53.3~+300 kPa** | **-53.3~+100 kPa**（±300mmHg，与测试负载自洽） | 🔴 **真空下限 -53.3**：泵虽可到 -58，阀在 -53.3 以下不能可靠切换 → 孪生真空渐近已改 -53.3（VALVE_P_MIN_KPA）。正压上限 >> 泵死点 61，不约束 |
| 耐压 | 350 kPa | 150 kPa | 密封能力远超工作区间 ✓ |
| 孔径 / Cv | **Φ1.2mm / Cv 0.05** | **Φ1.5mm / Cv 0.10** | 裸阀流导远大于孪生 VENT_C（差~2 量级）→ 实物排气比孪生快，到货 calibrate 重标；阀不是充压瓶颈（泵 2.2L/min 限制） |
| 响应时间 | **≤20 ms** | **≤30 ms** | << 50ms tick，孪生瞬时假设成立（依据入档） |
| 内部泄漏 | **≤30 mL/min**（规格上限） | ≤30 mL/min | 孪生 SEAL_LEAK 0.01/s≈3mL/min@40kPa·V5mL（好品假设）；上限≈0.073/s 的阀 4s 掉 25% → ML 判 major（设计意图：内漏超标=废品，该暴露） |
| 环境温度 | -10~+50 ℃ | -10~+50 ℃ | 室内 ✓ |
| 气嘴口径 | **Φ3.2 mm** | **Φ3.2 mm** | 🟡 手册实证"全系统最不确定接口"：4mm 内径管直插会漏，用 3mm 管直插（0.2mm 过盈）或 JT-709 变径（3.2→4.0）——装配指南预案已备 |
| 外形 | 19×19×61mm | 21×33×68mm（三口：底部两个+顶部一个） | 装配空间 |
| 寿命 | 通电 10s/断电 5s × **10 万次** | 同左 | 康复手套日 500 循环 → 200 天/阀，P1 选型关注 |
| 结构 | 直动式单线圈 | 两位三通"1→2 通；1→3 通" | F 通道逻辑到货吹气实测（公共口/常闭口/常通口对应） |

## 2. ✅ 0520D 阀型已定案：常闭（商家确认，2026-09-23 用户咨询）

**用户咨询商家结论：0520D = 常闭，0520C = 常开**（C/D 是该厂常开/常闭后缀——0520F 规格书里"D=常开"的命名规则描述系笔误或另有体系）。

证据复盘：规格书三处矛盾中，**标题"0520D常闭阀"是正确的**；模式栏"常开式"与 0520F 书"D=常开/F=常闭"命名规则均为厂商资料错误。教训入宪法实践：厂商资料内部矛盾时，纸面 2:1 证据链也会输给一句商家确认——**到货实测仍是最终判据**（装配指南 2.5 步保留为双保险，预期结果=断电不通气）。

影响：**保压架构成立**（断电=关闭 ✓），固件 `PN_VALVE_NORMALLY_OPEN=0`（NC 假设）正确，保持降占空比节能特性合法。

## 3. 两位三通的通道语义提醒

两位三通**永远有一条路通**（断电 1↔2、通电 1↔3 之类）——封不死单个气路，这是装配指南"保压必须常闭二通"判断的物理依据（套装三通常通问题同理）。0520F 在 P0 的角色是排气/泄压实验阀，不做保压密封。

## 4. ⚠ 2026-10-05b 图纸+实物照精读修正（本档案 §2 部分数据作废）

> 触发：用户问"还缺什么信息"例行复核时发现归档尺寸与 datasheet 图纸/实物照冲突（又一处"两说"），按用户原则当场裁定。

### 4.1 实物形态（⭐推翻"板载直插"假设）
- **0520D/F 均为"C 形硅钢架 + 红黑引线（终端 2P 白壳连接器）"形态，非 THT 直插**——
  PCB 连接改为 **11× 2P 卧贴插座**（JST-XH 2.54 系同族），阀体机械固定于印刷支架/歧管：
  D 用 C 架顶部 0.7mm 翻边；F 下单选**"有孔"变体**（⌀2.0 安装孔 ×2，datasheet 注明有孔/无孔两种）。

### 4.2 真实尺寸（图纸直读；原档案 19×19×61 / 21×33×68 **作废**——系含线/含包装误记）
| | 本体 | 气口 | 安装 |
|---|---|---|---|
| 0520D | **20.0±0.3 长** × ~13 × ~13mm（C 架） | 侧嘴 **⌀3.0×3.5**、顶嘴 0.7 凸台 | 架顶 0.7 翻边 |
| 0520F | **15.2(+.3/-.1) × 13.0(+.3/-.1) × 17.5mm** | 底口 **⌀3.5×2（间距 10.0）**、顶口 **⌀3.0×7.0**、总长 38.0 | ⌀2.0 孔×2 |

- 管径结论不变：⌀3.0~3.5 嘴 → 3mm ID 硅胶管 ✓（与传感侧统一）。
- devices.json dims 待 T1 重录（含 port 布局：F=底 2 顶 1，D=侧+顶）。

### 4.3 F 端口语义（实物标签+图纸一手确认 ✓ 与本档案 §2 一致）
通电 1↔2 通（1=COM、2=NO）；断电 1↔3 通（3=NC）。实物标签 "VALVE 0520F DC4.5V"。

### 4.4 电流"两说"（新发现，设计已按最坏情况兜底）
- datasheet 文本层（D/F 同文）：**240mA / 1.6W**——内部不自洽（240mA×4.5V=1.08W≠1.6W），
  且 D 文"常开式"vs 同页"常闭式"、F 文"两位两通"vs 标题"两位三通"——范文级抄写错误，
  240mA 疑为系列大兄弟型号 boilerplate；
- 本档案 §2 原记：D **85mA/0.38W**（自洽 ✓）、F **320mA/1.44W、线圈 14.1Ω**（三重自洽 ✓，
  2026-09-22 商家确认）；
- **裁定：预算按最坏 240mA/只**——1f-β 最坏并发 10 阀（S+V+8D）=2.4A+泵 0.5A=**2.9A<3A 仍成立** ✓；
  驱动件（AO3400 5.7A/SS14 1A）两说下均富余 ✓；
- **关闭路径**：BRINGUP 万用表测线圈电阻一锤定音（≈19Ω→240mA 档 / ≈50Ω→85mA 档 /
  ≈14Ω→320mA 档）+ 可选请卖家订单备注确认 listing 电流表；
- 连带：若 240mA 为真，多阀并开壳内发热 ~1W/只 → T6 留通风并记录测试工况。

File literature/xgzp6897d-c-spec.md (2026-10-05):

# XGZP6897D-C 全参数归档（🅰 官方 V1.1 datasheet 16 页完整版，2026-10-05 用户提供）

> 本文件取代此前"深挖文本层"的片段记录——用户供全 pages 后逐页精读，电气/几何/协议/工艺
> 四类真值一次配齐。BOM 选型码：**XGZP6897D-C100KPDPN**（-100~100kPa 表压 DPN，I2C 0x58）。

## 1. 性能指标（供电 5±0.25V DC，25°C 参考）

| 项目 | 数值 | 备注 |
|---|---|---|
| **精度 ±2.5 %FS** | 线性+重复性+迟滞合成；量程不同精度不同（可询厂） | ±100kPa 档 ≈ ±5kPa；康复控制目标 ±5kPa 级可接受；出厂校准收紧零点/增益，线性/迟滞定下限；高精度可定制小量程 |
| 零点漂移（回流后） | ±1.0 %FS | 回流焊后需置零校准（固件开机置零策略） |
| 过载压力 | 2.5×（10<FS≤100kPa 档）；P2 端过载上限 250kPa | ±100kPa 档过载 250kPa，包络充裕 |
| 补偿/工作/贮存温度 | 0~60 / -30~100 / -40~125 °C | |
| 上电启动 / 响应 | 24ms / 2.5ms@OSR_P=1024 | 控制环 ≥100Hz 无压力 |

## 2. 电气特性

- 供电 2.7~5.5V（LDO 3.0V 内置）、待机 100nA、PSRR 60dB；
- **压力 24bit / 温度 16bit** 分辨率；内置温度传感 ±1°C；
- I2C ≤**400kHz**、地址 0x58、SDA/SCL 上拉典型 4.7kΩ；
- ESD HBM ±2000V；**过载电压 6.5V/电流 5mA 即烧毁**（ESD 防护注意）。

## 3. 引脚与外形（GB/T1804-M 未注公差）

**引脚**：2=VDD / 6=SDA / 7=SCL / 8=GND / **1-3-4-5=N/C（严禁连接，否则功能失效——footprint 必须悬空处理）**；VDD-GND 就近 0.1µF（设计已含）。

| 几何项 | 值 |
|---|-----|
| 本体 | 10.6±0.2 × 7 × 3.5mm（11mm 含引脚总长） |
| 倒钩 ×2 | 高 2.4mm、外径约 ⌀3.22/颈 ⌀2.2、**内孔 ⌀0.9**；**P1=高压端（默认）/ P2=低压端** |
| 总高（含倒钩） | 9.5mm |
| **倒钩接管** | 3mm ID 硅胶管过盈（**与阀侧 Φ3.2→3mm 管一致**，管系统一）；内孔 ⌀0.9 为死端引压口，不碍主流路 |
| 焊盘 | 2.54mm 节距 ×4+4、焊盘 0.9×2、排距 7.96、footprint ~12×12mm（T3 建封装直接用；倒钩让位另计） |

## 4. I2C 寄存器手册（T7 固件驱动直接落地）

- 读数据：上电 → 从 **0x04 连续读 5 字节**（ASIC 自动刷新）：前 3 字节压力、后 2 字节温度；
- 压力：`sum = b0<<16|b1<<8|b2`（24bit 补码，>8388608 减 2^24）→
  `P[Pa] = sum/2^21 × (PMAX-PMIN)`，±100kPa 档 PMIN=-100000/PMAX=100000；
- 温度：`RAW_T` 组合后按 0x20/0x21 系数寄存器换算（EOFF=±4096/8192/16384，
  Shift_N=Byte2/10 ∈ {7,6,5.5}）→ `T = (Inter_T-Byte1)/2^Shift_N + 25`；
- 寄存器：0x00 ID=0x58 / 0x01 Chip_Control（Active、测量选择、data_ready）/
  0x02 CFG_OSR（压力/温度过采样 256~32768×、MODE：睡眠/正常/单次/循环）/
  0x03 CFG_MEAS（PT 比、待机 0~2000ms）/ 0x04-06 P_data / 0x07-08 T_data / 0x24 DAC_EN；
- 单次采集模式（One shot）+ 24ms 启动 → 1× 分时扫描时按需唤醒可省电。

## 5. 选型指南（页 4 量程表，BOM 关闭缺口③）

`XGZP6897 D C [量程000-999] [MP/KP/HP] [DG 正压/DGN 负压/DPN 负到正]`

| 候选 | 量程 | 判定 |
|---|---|---|
| **C100KPDPN** | **-100~100kPa** | ✅ **选定**：包络 -50~+50 工作带 2× 裕量，标准量产档 |
| C040KPDPN | -40~40kPa(-300~300mmHg) | ✗ 真空 -50kPa 出程 |
| C100KPDN | -100~0 | ✗ 无正压 |
| 定制 -60~60 | 可定制(000-999) | P2 备选：精度 ±2.5%FS→±3kPa，询厂交期 |

## 6. 工艺/可靠性红线（页 9-10）

回流 ≤200°C 峰值（推荐 190）/ 手焊 190°C≤5s / **避免 DIP 焊**（热容小易变形）/
板翘 <0.05mm / 开放构造禁清洗液入内、禁超声清洗 / 非防滴、防凝露/结冰 /
**芯片避光**（透明管路遮光）/ 压力口禁插针状异物、P2 大气口勿堵塞 /
储存氮气柜、端子导电材料短路存放（ESD）。

## 7. 与架构的耦合校验（1f-β / 决策 3）

- 1× 分时：传感倒钩接公共歧管 M 测量位（死端引压），P1 接管、P2 大气开放→表压读数 ✓；
- 8× 并行：同码器件 ×8 + TCA9548A（0x58 固定地址）✓；逐只 ±2.5%FS 偏移差异→出厂校准表；
- 开机置零：回流零漂 ±1%FS → 固件上电且确认全阀关断时执行零点基准采样。

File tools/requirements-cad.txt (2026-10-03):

# tools/venv-cad — CAD 几何核运行环境 (spec: device-geometry D2/L5)
# 重建: python -m venv tools/venv-cad && tools/venv-cad/Scripts/python -m pip install -r tools/requirements-cad.txt
#   (需代理时加 --proxy http://127.0.0.1:7877)
python-fcl==0.7.0.11
trimesh==5.1.1
networkx==3.7
scipy
numpy

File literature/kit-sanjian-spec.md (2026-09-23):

# 呼吸气球套装散件资料摘要（1688 创客电子 LN-3-50W-DOB）

> 来源：`E:\FLOWIO\资源\散件.pdf`（9 页商品详情截图，纯图片）
> 归档日期：2026-09-23 · 渲染页 `资源/sanjian_p1..9.png`
> 用途：P0 压力源级（泵+两只三通阀+三只舵机开关）+ 测试气囊 + 管路

## 1. 清单确认（p9 产品清单，与 BOM 记录一致）

白色主控盒×1（TYPE-C 5V 供电口）、370 充吸两用泵×1、两位三通电磁阀×2、
舵机式 PWM 电子开关×3、波浪纹气球×3、硅胶管 4×6mm×2m、三通/变径接头若干。
散件不含控制板/电池/遥控（我们不要它的 ESP8266 板）。

## 2. 内部布局（p3 爆炸图）

主控盒内：泵 + 充气三通阀 + 吸气三通阀 + 泵开关 + 充气阀开关 + 吸气阀开关
——**1 泵 + 2 阀 + 3 舵机开关**，与 HAL 映射（pump/inlet/vent 各一只舵机开关）一致。

## 3. 舵机式 PWM 电子开关（p6，逐字）

- **工作电压 3-5V，最大电流 2A，直通型（输入多少 V 输出多少 V）**
- **180°=接通 / 0°=关断**；**50Hz 舵机 PWM 信号**
- 线序：红=VCC、黑=GND、白=信号
- 与固件 HAL 对应：RMT 50Hz，脉宽 500µs=0°(关)、2500µs=180°(开) ✓ 语义已对齐
- ⚠️ 2A 上限：泵启动峰值 ~1A 内 ✓；**只有通/断两态，不支持 PWM 调速/保持降压**（这正是必须外加 MOS 模块的原因，BOM 依据成立）

## 4. 370 泵（p7）

DC 5V、充吸两用、红=VCC 黑=GND。完整参数以 FIT0801 规格书为准
（`370-pump-FIT0801-spec.md`：≥-58kPa、2.2L/min、嘴 ⌀4.3±0.2mm）。

## 5. 套装两位三通电磁阀（p8，复核后仅此一条可靠）

⚠️ 识别勘误：首轮 OCR 报出的"320mA/Φ1.5/Cv0.10"等参数经单页复核**确认为幻觉**
（图上无此字样）——套装三通阀的可靠参数**只有阀体标签 "DC 4.5V"**。
电流/孔径/通道逻辑到货万用表+吹气实测（装配指南四.2.5/第五节）。
教训入宪法实践：关键参数必须单页复核可见字样，多图并发识别的"完美对齐"结果要怀疑。

## 6. 气路拓扑（p5）

泵充气口→充气三通阀→汇流；泵吸气口→吸气三通阀→汇流；三通对外孔通大气；
硅胶管 **4×6mm**（内径 4mm）——与装配指南管路设计一致。

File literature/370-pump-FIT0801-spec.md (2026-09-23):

# 370 Mini Vacuum Pump 规格档案（DFRobot SKU: FIT0801）

> 2026-09-22 建立 | 触发：用户质询"370 泵有没有手册？没有的话孪生参数是瞎猜"
> 四源交叉一致（DFRobot / Mouser / RobotShop / Schematik）。
> **原件已入库**：`370-pump-FIT0801-datasheet.pdf`（2 页，Mouser Product Overview，
> 2023-01-09 版，用户浏览器代下——宪法第 27 条协议首次执行）。
> **本档是孪生泵参数的正源之一（PHYSICS-SPEC §泵参数溯源）。**

## 规格表

| 参数 | 规格值 | 备注 |
|---|---|---|
| 工作电压 | 1.5 ~ 5 V DC | kit 按 5V 供电 |
| 功率 | ~2.5 W（5V） | 启动瞬间 ~1A（采购清单风险项已记） |
| 空载电流 | ≤ 500 mA（5V） | |
| **空载流量** | **≥ 2.2 L/min（5V）** | = 0.0367 L/s 自由流 |
| **最大真空（死点）** | **≥ -58 kPa** | 充吸两用，反接极性换向 |
| 最大正压 | 型号相关（约 60-100 kPa） | 规格书未给单值，**到货实测** |
| 噪音 | < 60 dB | |
| 电机 | 370 有刷（Mabuchi 370 族） | 不适合长时间连续运转 |

## 外形尺寸（规格书第 2 页图纸，2026-09-22 提取）

| 部位 | 尺寸 (mm) | 用途 |
|---|---|---|
| 泵体总长 | **58 ±0.5** | 布局 |
| 泵头段 | ⌀27 ±0.3 × 长 27.3 | 布局 |
| 电机段 | ⌀24.2 | 布局 |
| **气嘴（进/出口）** | **⌀4.3 ±0.2，伸出 7** | **→ 4mm 内径硅胶管直插 = 0.3mm 过盈自密封，无需变径** |
| 端面特征 | 孔距 10 / 槽 18.0 / 槽宽 2.0 | 定位/安装（图纸分辨率有限，到货卡尺复核） |
| **重量** | **规格书未给** | 到货称重补记（B2B 重量预算需要） |

阶段判定（2026-09-22）：P0 无需外形设计（面包板+扎带）；尺寸成为硬约束的时点 =
P1/PCB 器件布局（58×27 泵体 + 5 阀 + 汇流管 → 板形）与 Pro 版控制盒外壳设计。

## 对孪生参数的直接修正（2026-09-22 落地）

| 孪生常数 | 旧值（借 FlowIO Small） | 新值/状态 | 依据 |
|---|---|---|---|
| `PUMP_P_MIN_KPA` | -38.0 | **-58.0** | 本规格书"≥-58 kPa"（同型号泵，强于 FlowIO 借值） |
| `PUMP_P_MAX_KPA` | 61.0 | 暂保持 61.0 | 规格书正压无单值（60-100 型号相关）；FlowIO 实测 61 仍在带内；到货实测后定 |
| `PUMP_C` | 9e-8 | 暂保持 | 见 PHYSICS-SPEC"时间尺度"节：孪生按 FlowIO 实测充压曲线（大容积执行器）标定；370 直驱 7mL 汇流管理论上更快（~0.037 L/s 自由流），对 ML 标签无影响（泄漏检测在密封态，与泵时标无关），到货用 calibrate_pump.py 重标 |

## 来源

- **原件 PDF**：`370-pump-FIT0801-datasheet.pdf`（本目录，pypdf 已验：2 页 + 规格逐项核对）
- DFRobot 官方产品页（SKU FIT0801，$5.50）：product-2374.html
- Mouser（原件出处）、RobotShop、Schematik（转售页同表交叉）

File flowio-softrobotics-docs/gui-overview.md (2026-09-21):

# GUI Overview

> Source: https://www.softrobotics.io/gui-overview

The Graphical User Interface (GUI) for FlowIO runs in the web-browser. And as such, you don't need to download or install anything in order to use FlowIO. You simply launch the GUI web page and click the connect button to establish a Bluetooth connection between your web-browser and the FlowIO device.

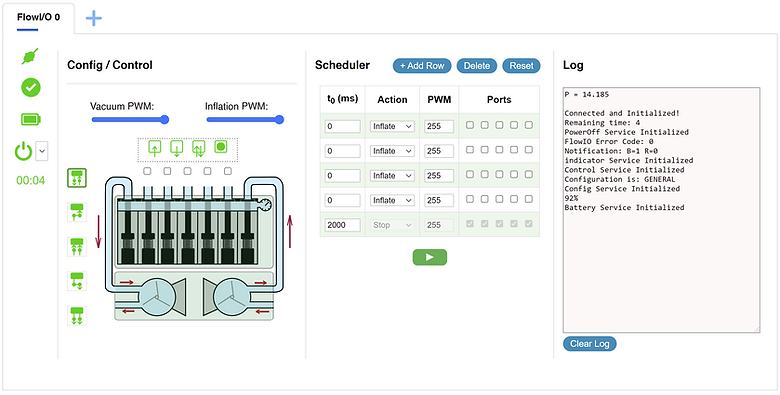
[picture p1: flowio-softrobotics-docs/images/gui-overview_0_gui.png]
(https://www.softrobotics.io/gui)


Sidebar:

At the top of the sidebar the "Connect / Disconnect" button, which you press to connect to or disconnect from a FlowIO device. The button also also shows the current connection status. Underneath it are icons for device status, battery level, and a power off button with an Auto-Off timer. By default, the device is set to power itself off after 5 minutes of inactivity.

Scheduler:

A dynamic task scheduler allows you to define and execute a sequence of actions. Each row of the table lets you choose the starting time of the action in milliseconds, the type of pneumatic action, the PWM value for the flow rate, and the port(s) on which that action should take place. You can add as many tasks to the table as desired by clicking the "Add Row" button above the table. Once you have set your sequence parameters, you just click the play button to execute the sequence.

Config/Control:

An interactive device graphic showing the complete pneumatic representation of the connected FlowIO device, including the 7 valves, 2 pumps, and the connections between them. The graphic is interactive and dynamic to lets you see exactly what is happening inside the FlowIO device in real-time as you as you are working with the device.

The 5 checkmarks above the graphic correspond to the 5 pneumatic I/O ports. To choose which port(s) you want to work it, simply check the desired port(s). 

The 4 buttons above the checkmarks are the pneumatic action buttons for Inflation, Vacuum, Release, and Stop. For example, if you want to start vacuum on ports 3 and 4, you would put a checkmark in those 2 ports and then click on the vacuum button.

The two blue sliders above the buttons control the flow-rate the inflation and vacuum pumps, by controlling the PWM values of the signal driving each pump.

The 5 buttons to the left of the graphic allow you to change the pneumatic configuration between General, Series Inflation, Series Vacuum, Parallel Inflation, and Parallel Vacuum. Changes in the pneumatic configuration are immediately reflected in the interactive graphic. 

Log:

A status log showing real-time device feedback. In the status log, you can read information about the everything that is happening to the device, as well as readings from the various sensors embedded inside FlowIO. 

Tabs (top):

The GUI is tab-based to allow you to connect allows multiple FlowIO devices simultaneously. If you want to connect a second FlowIO device, simply click the blue "+" button to add another device tab with its own independent set of controls. You connect and control several FlowIO devices to the same interface.

[Get Involved ](https://www.softrobotics.io/contribute)

Find out how you can help

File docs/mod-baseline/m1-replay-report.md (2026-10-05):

# M1 确定性生成器重放对拍报告（hw/geom/flows 域挂载 · 2026-10-05）

> 基线：docs/mod-baseline/baseline.json @7885c62（M0 冻结）
> 对拍原则：迁移只做"代码搬迁 + import/路径解析改经 flowio 包定位"，生成逻辑零改动。
> 证明方式 = 同机同版本重放：**旧代码重放 ↔ 新代码重放 ↔ 仓内 committed 产物** 三方对拍。

## 一、重放矩阵（任务指定的 7 个确定性生成器）

| 生成器 | 旧侧 | 新侧 (flowio.*) | 归一化器 | 结论 |
|---|---|---|---|---|
| make_case | committed @53f8953 | flowio/geom/make_case.py | STEP: FILE_NAME 时间戳→`<TS>` | **STL 逐字节一致**（528484/397584 B）；STEP 归一化一致（仅时间戳 15 B 差） |
| make_manifold | committed @53f8953 | flowio/geom/make_manifold.py | 同上 | **STL 逐字节一致**（839584 B = baseline sha c485460be3d7）；STEP 归一化一致 |
| make_pump_module | committed @53f8953 | flowio/geom/make_pump_module.py | 同上 | **STL×3 逐字节一致**（19884/15084/44884 B）；STEP×3 归一化一致 |
| make_meshes | committed @53f8953 | flowio/geom/make_meshes.py | 无需（逐字节） | **11 产物全部逐字节一致**（含 valves.stl/tubes.stl/assembly.json 三个基线产物） |
| make_assembly | @53f8953 沙箱重放（同等输入） | flowio/geom/make_assembly.py 沙箱重放 | STEP 时间戳 | **STL 逐字节一致**（5447284 B）；STEP 归一化一致 |
| make_flows | @53f8953 沙箱重放 | flowio/flows/make_flows.py | 无需 | **flows.json + hotspots.json 双双逐字节一致**（旧↔新） |
| gen_sch | @393caac~1 沙箱 cwd 重放 + committed | flowio/hw/sch_gen.py | uuid4→`<UUID>` | **三方归一化逐字节一致**（448482 B raw，committed sha f9d15ecde811 不变） |

- make_assembly 输入 fab/flowio-p1.step 为 gitignored 按需产物（仓内无存），本次经
  `kicad-cli pcb export step` 现导（**板文件 sha 前后均为 be35ebc7cff8，只读验证**）；
  无器件模型（14 solids vs 原 500+）→ 两侧同等松开 `solid>=500` 质量门后对比，输入完全相同。
- gen_sch 的 uuid 归一化覆盖 root uuid/实例 uuid/junction/wire/label/no_connect/text 全部 uuid4 现场。

## 二、额外（超出任务清单的加固验证）

**gen_pcb（⛔ 本身禁重放，沙箱隔离验证 AST-PARTS 提取机制迁移无漂移）**：
旧 tools/gen_pcb.py ↔ 新 flowio/hw/pcb_gen.py 在各自沙箱（输出路径均封闭在 .tmp_replay/）
经 KiCad python 各生成骨架板 → uuid 归一 + 行排序指纹（KiCad 存盘按随机 KIID 排序 footprint，
顺序不稳定属工具行为）→ **指纹相等**（7589ab888fefeaa7，1026307 B）。真实板文件全程未动。

**make_bom（AST 读源路径迁移的回归）**：经新读源路径 flowio/hw/sch_gen.py 重放，
BOM 146 refs == CPL 147 refs 对拍一致，fab CSV 产物零字节改动。

## 三、产物不可变门（compare_baseline --products）

11 产物 sha256[:12] 全等（**含 .kicad_pcb / .kicad_sch / jlc.zip**）：

```
kicad_sch f9d15ecde811 | kicad_pcb be35ebc7cff8 | jlc.zip 7bd6420a76a1
manifold c485460be3d7 | pump-module 1e23604a63d7 | case-top d5344d928e86
case-bottom 1a51551d3f44 | assembly.json 0630def517d1 | flows.json 9f9b175a0076
valves.stl 1d30029a599e | tubes.stl 91fd51db5306          —— 23 ok / 0 bad
```

重放后的覆写产物一律 `git checkout --` 还原；最终 `git status` 干净（仅 gitignored 构建产物）。

## 四、测试全家桶（迁移后全量重跑）

| 层 | 结果 |
|---|---|
| flowio core（M0） | OK（errors/interfaces/TruthSource/views） |
| L1-L3 test_assembly | **30/0** |
| L4 test_assembly_freecad | **5/0** |
| L5 test_device_geom schema / all | **15/0 / 13/0** |
| test_flows | OK（16 elec + 12 air + 6 hotspots 断言） |
| device_graph | **21↔21 完美匹配** + flows 交叉校验 0 违例（新路径与旧 shim 双验证） |
| electrical_sim | 6 testfns OK |
| 场景矩阵（compare_baseline） | **12/12** 数值相等 |
| test_api（run_tests.sh 内） | **50/50**（初版误记 51 —— 含汇总行 "✓ 接口测试 50/50" 的计数偏差，实为 50 项 ✓ / 0 ✗） |
| test_gui / test_e2e | SKIP（playwright-core 本机未装，基线期即如此的环境前置，非 M1 回归） |

## 五、发现（非 M1 引入，如实记录；①② 已在 M1 评审修订窗修复）

1. **hotspots.json 陈旧漂移（预存在，✅ 已修 M1-R3/372c739）**：仓内 hotspots.json 的
   U2 盒尺寸 [4.9,3.9,1.75]（SOP 关键词命中）为 T3c（2922724）产物；T6-0（b4512ff）
   关键词改按长度降序后正确匹配为 TSSOP [7.8,4.4,1.1]，但 **hotspots.json 自 T3c 后
   从未再生成**。初轮重放旧↔新互为逐字节一致（证明迁移零漂移），M1 主体遵守"产物
   一字节不动"保留旧值；修订窗经 make_flows 重放至真值（U2 TSSOP + U3 SOIC，U3 见②）
   并 build_site 同步，flows.json sha 9f9b175a0076 复核不变。
2. **case_geom 的 devices.json 加载恒走回退分支（预存在，✅ 已修 M1-R2/6829e92）**：
   `_load_device_dims/_load_pneu` 引用 `Path` 但模块只 `import struct` → NameError 被
   宽 except 吞 → 常驻走内置兜底表。初版论断"兜底与真值等价"**被规格评审证伪**：
   实为**电子 3 键不等价（L1=IND-SMD / LED1=5050 / U3=SOIC，兜底无关键词退化
   DEFAULT_DIM）+ 气动 14 键等价**。修复：补 `from pathlib import Path`，加载路径经
   包定位指 enclosure/ 原位**单源**（不拷贝——拷贝即第二真值必分叉；兜底表保留作
   仓库外降级）。验证：高度链不变（TALLEST 9.5）→ 11 产物 sha 仍全等；parts_f.stl
   重放顶点级证明恰 3 盒变更（24+24 顶点、盒外零漂移）；L4 5/0 + diag_l4 total=0.0000
   （3 个变大电子盒无新干涉）。
3. **check_fab "zip↔散件逐字节一致" 检查红（预存在，未修——工具侧问题非产物问题）**：
   jlc.zip 内 Gerber 为 CRLF，仓内散件在基线提交（7885c62）即为 LF（提交时换行归一化），
   行数/内容逐行相等、仅换行符差 → 字节级比较必红。zip 本体 sha 与基线一致（下单件
   不受影响）。M1 全程未触碰 fab 产物（git status 干净为证）；建议 check_fab 改为
   换行归一化后比较（留待 fab 工具链窗口）。

## 六、M1 评审修订窗补录（R1-R3，2026-10-05 规格审"有条件合规"项）

| 项 | 内容 | commit |
|---|---|---|
| R1 必修 | tools/ 三 runpy shim `_ROOT` dirname×3→`Path.parents[3]`（tools 深 4 级，×3 只解到 hardware/，三 shim 均不可跑）；修后实跑证明：gen_sch shim 出图 parts=160/stubs=415、gen_pcb shim "骨架 164 封装"、route_pcb shim argv 透传 stage1 完成——均 sha 守卫（sch f9d15ecde811 / pcb be35ebc7cff8 跑后还原复核） | 18fe453 |
| R2=E② | case_geom Path 修复 + 单源加载（见发现②），parts_f.stl 真值重放 + site 同步 | 6829e92 |
| R3=E① | hotspots.json 真值重放（U2/U3）+ build_site 同步（site 其余 28 文件字节稳定） | 372c739 |

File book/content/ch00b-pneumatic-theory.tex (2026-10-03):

\chapter{气动软体机器人驱动与控制}
\label{ch:pneu-theory}

第~\ref{ch:twin} 章的孪生物理引擎 v2 里跑着三条方程：多变气体定律、ANSI 孔口流量、RC 集中参数类化。它们不是本书的发明，而是气动软体机器人社区近十年的公共财产——大部分来自 Xavier、Fleming 与 Yong 的系列工作与 Facebook Reality Labs 的气路响应时间模型。本章把这些方程的来历、适用条件与推荐参数讲透；第~\ref{ch:twin} 章只是它们的工程化读者，本章是文献意义上的原始出处课。同样重要的一半是\textbf{装置史}：从 PneUI 到 FlowIO 的交互装置脉络与从拇指手套到织物综述的康复前沿，共同构成 FLOWIO-CN"分指压力闭环 + B2B 白牌"定位的参照系。

\section{驱动方式谱系：为什么是气动}
\label{sec:pneu-actuation}

软体机器人的"软"来自执行器，驱动执行器的能量形式却只有有限的几条路线。Xavier 等在其非线性控制器综述的引言里列举了软机器人常用的驱动族：介电弹性体、气动、液压、形状记忆合金（SMA）等~\cite{Xavier2022Frontiers}。把工程约束（响应速度、功率密度、驱动电压、可微制造性、成本）压上去，谱系就收窄了，见表~\ref{tab:pneu-spectrum}。

\begin{table}[htbp]
  \centering
  \caption{软体执行器主流驱动方式谱系}
  \label{tab:pneu-spectrum}
  \begin{tabular}{lp{2.6cm}p{2.4cm}p{3.6cm}}
    \toprule
    驱动方式 & 代表特征 & 主要瓶颈 & 在本书场景的裁决 \\
    \midrule
    气动（流体） & 响应快、力量/重量比高、执行器即气囊 & 需泵阀气路与传感闭环 & \textbf{选定}：康复手套事实标准，白牌厂商工艺成熟 \\
    SMA 形状记忆 & 结构极简、可直接电驱动~\cite{Sansone2022} & 热惯性慢、迟滞大、效率低 & 放弃：分指节拍 (秒级热循环) 撑不住训练密度 \\
    介电弹性体 & 应变大、速度快 & 千伏级驱动电压 & 放弃：人体穿戴安全与绝缘成本 \\
    绳驱/腱鞘 & 传动成熟、电机生态好 & 摩擦/迟滞、非软体本体 & 部分竞品采用；与织物气囊工艺不亲 \\
    \bottomrule
  \end{tabular}
\end{table}

SMA 一支值得多说一句：Sansone 等 2022 年在 \emph{Actuators} 上完成了 SMA 扭转执行器从概念设计到初步设计的完整方法学~\cite{Sansone2022}——这类工作证明了替代路线的成熟度，也反衬了它的边界：热驱动的高能量密度换不来快响应与低迟滞，而康复训练恰恰要求高频、可重复、可计量的节拍。气动的"短板"（需要一套泵阀传感系统）在本书语境里不是缺点，而是\textbf{产品本身}——驱动系统做对了，气动路线的全部优点都被执行器侧继承。

\section{气动系统建模：三条方程与一个类化}
\label{sec:pneu-modeling}

\subsection{多变气体定律：压力动力学的主方程}

Xavier 等 2020 年 AIM 论文 \emph{Modelling and Simulation of Pneumatic Sources for Soft Robotic Applications}~\cite{Xavier2020AIM} 给出了软体机器人气源建模的热力学起点：理想气体假设下，控制体内压力的一般变化由能量方程导出，对多变过程（polytropic，指数 $\gamma$ 从等温 1.0 到绝热 1.4）可写成

\begin{equation}
\Delta P = \frac{\gamma R T}{V}\left(\dot m_{\mathrm{in}} - \dot m_{\mathrm{out}}\right) - \frac{\gamma P}{V}\Delta V,
\label{eq:pneu-energy}
\end{equation}

即压力变化由\textbf{净质量流入}与\textbf{边界变形}两项竞争~\cite{Xavier2020AIM}。若以体积流量 $Q$（而非质量流量）表出、腔体容积暂视作常数，就得到本书孪生每 50\,ms tick 积分一次的主方程（Xavier 2022 前述综述 Eq.2/Eq.4 的形式~\cite{Xavier2022Frontiers}）：

\begin{equation}
\frac{\mathrm{d}P_A}{\mathrm{d}t} = \frac{\gamma P_A}{V_A}\, Q,
\qquad Q = Q_c - Q_d .
\label{eq:pneu-dpdt}
\end{equation}

多变指数怎么取？\cite{Xavier2020AIM} 的建议是 $\gamma=1.2$：充气过程偏绝热、放气偏等温，实验与仿真落在两者之间；且多数软体机器人工作在 100\,kPa、10\,SLM 以下，过程"更靠近等温"。这条经验值被本书孪生原样继承（第~\ref{ch:twin} 章参数表 $\gamma{=}1.2$），\cite{Xavier2020AIM} 同时报告：计入壁面换热只带来约 10\% 的差异——对工程孪生，经典多变模型已是足够的精度。

\subsection{孔口方程：流量的两个分支}

压力动力学里的 $Q$ 从哪来？对阀控系统，Xavier 2022 采用 ANSI/(NFPA) T3.21.3 阀流量模型~\cite{Xavier2022Frontiers}：体积流量（L/s）随占空比线性标度、随上下游压差平方根增长：

\begin{equation}
Q = 114.5\, u\, C_v \sqrt{\frac{P_{\mathrm{low}}\,\Delta P}{T_{\mathrm{high}}}},
\qquad \Delta P = P_{\mathrm{high}} - P_{\mathrm{low}},
\label{eq:pneu-ansi}
\end{equation}

其中压力取绝对压（bar）、温度取开尔文，$C_v$ 为流导系数，$u\in[0,1]$ 为 PWM 占空比——"泵/阀 PWM 线性标度流量"这条被 FlowIO 工程化~\cite{Shtarbanov2021} 的经验律，在孔口模型里就是 $u$ 的线性因子。把充气（上游为汇流管/储气罐 $P_R$）与排气（下游为大气 $P_{atm}$）两支代入式~\eqref{eq:pneu-ansi}，整理即得孪生 v2 的充气渐近死点行为：$Q_c \propto \sqrt{P_A(P_R-P_A)}$，当腔压逼近气源压力时流量自然趋零~\cite{Xavier2022Frontiers}。

式~\eqref{eq:pneu-ansi} 是\textbf{亚音速分支}。当上下游绝对压比超过空气临界压比（约 1.893）时，孔口流速钳制在音速，流量不再随 $\sqrt{\Delta P}$ 增长——即 choked flow（阻塞流）。这正是本书孪生对 $f = P_{\mathrm{low}}\Delta P$ 项做上下钳位的物理依据（第~\ref{ch:twin} 章），其可观测签名是泄放初期降压速率近似恒定、之后才转入平方根衰减尾。选型层面，阀的流通能力以 ISO 6358 声导 $C$（L/(s$\cdot$bar)）给出，可换算为 ANSI $C_v$~\cite{Xavier2022Frontiers}——\cite{Xavier2022Frontiers} 给出的完整选型流程（目标压力/上升时间 $\to$ 储气罐容积 $>$10 倍腔体 $\to$ 声导下限 $\to$ 泵流量下限）是 FLOWIO-CN 泵阀选型的模板。

\subsection{集中参数类化：RC 电路的气动镜像}

第三条方程是\textbf{类化}而非方程本体：压力 $\leftrightarrow$ 电压、体积流量 $\leftrightarrow$ 电流，气路元件即可写成~\cite{Xavier2020AIM}

\begin{equation}
R = \frac{128\,\mu\, l}{\pi d_h^4},
\qquad C = \frac{V}{\beta},
\qquad L = \frac{\rho\, l}{A},
\label{eq:pneu-rc}
\end{equation}

气阻（管道沿程损耗，$\mu$ 黏度、$d_h$ 水力直径）、气容（$V$ 容积、$\beta$ 体积模量；多变过程下 $\beta = \gamma P$）、气感（管内流体惯性）。以此类化，\cite{Xavier2020AIM} 把"理想泵直充""泵 + 泄漏""泵 + 管路""泵 + 储气罐 + 执行器""带压力控制的全系统"五种工况逐一写成常微分方程——例如含泄漏的直充工况为 $\mathrm{d}P_a/\mathrm{d}t = (\gamma P_a/V_a)Q_c - (\gamma P_a^2)/(V_a R_c)$，泄漏项以 $P^2$ 增长，最终压力稳定在源流量与泄漏平衡处。

同一类化的实验验证来自 Stanley 等 2021 年（2020 年在线）的 ASME 论文~\cite{Stanley2021}：他们对 100\,$\mu$m--1\,mm 的流阻、5--200\,kPa 气源、0.5--16\,mL 容积的组合系统标定了 RC 响应时间模型，63.2\%（$1-1/e$）充放气时间的预测与实测的决定系数达 $r^2 = 0.983$，响应时间从毫秒级到秒级全覆盖。对本书的直接意义：汇流管 + 端口气腔的每个通道都是一阶 RC 系统，闭环带宽、阀 PWM 频率、孪生积分步长的量级估算都以此为尺。三条方程汇总见表~\ref{tab:pneu-eqs}。

\begin{table}[htbp]
  \centering
  \caption{本书孪生物理 v2 的三条方程与文献出处（详细对应见第~\ref{ch:twin} 章表）}
  \label{tab:pneu-eqs}
  \begin{tabular}{lp{4.4cm}p{2.2cm}}
    \toprule
    规律 & 采用形式 & 出处 \\
    \midrule
    压力动力学 & 式~\eqref{eq:pneu-dpdt}，$\gamma{=}1.2$ & \cite{Xavier2020AIM,Xavier2022Frontiers} \\
    阀孔流量 & 式~\eqref{eq:pneu-ansi} + 音速阻塞钳位 & \cite{Xavier2022Frontiers} \\
    气路类化 & 式~\eqref{eq:pneu-rc}，RC 响应时间 $r^2{=}0.983$ & \cite{Xavier2020AIM,Stanley2021} \\
    \bottomrule
  \end{tabular}
\end{table}

\section{从方程到选型：0520D 与 0520F 的实物对照}
\label{sec:pneu-valves}

方程与谱系之后，落到采购单上的是两只具体的小电磁阀。FLOWIO-CN P1 的 7 只阀取自国产 0520 系列的两条产品线：\textbf{0520D（常闭二通）}与 \textbf{0520F（两位三通）}，两份中文规格书随采购件存档~\cite{valve-0520d-ds,valve-0520f-ds}。线圈侧两者同族：额定 DC 4.5\,V、240\,mA、1.6\,W、孔径 0.45\,mm、介质空气；分野在\textbf{流路拓扑}——二通常闭阀断电即密封，天然表达"保压"语义（FlowIO 的常闭阀选择~\cite{Shtarbanov2021} 在此获得国产现货对应物）；两位三通阀的通/断两态各接一个端口，一只阀即可完成方向切换。本书的用法：端口阀取 0520D（保压为默认态），进气/排气方向组合取 0520F。表~\ref{tab:pneu-valves} 把规格书首页可核参数与孪生物理（PHYSICS-SPEC）的派生采用值并排放置。

\begin{table}[htbp]
  \centering
  \caption{0520D vs 0520F：规格书首页可核参数（上五行~\cite{valve-0520d-ds,valve-0520f-ds}）与孪生采用值（下三行，派生依据见第~\ref{ch:twin} 章参数表）}
  \label{tab:pneu-valves}
  \begin{tabular}{llp{5.2cm}}
    \toprule
    项 & 0520D & 0520F \\
    \midrule
    流路拓扑 & 常闭二通 & 两位三通 \\
    额定/工作电压 & DC 4.5\,V / 4.1--5.0\,V & DC 4.5\,V / 4--5.5\,V \\
    线圈电流/功率 & 240\,mA / 1.6\,W & 240\,mA / 1.6\,W \\
    公称孔径 & 0.45\,mm & 0.45\,mm \\
    介质 & 空气 & 空气 \\
    \midrule
    裸阀流导（孪生） & $C_v$ 0.05 & $C_v$ 0.10 \\
    响应（孪生瞬时假设依据） & $\le$20\,ms & $\le$30\,ms \\
    动作压力下限 & \multicolumn{2}{l}{$-53.3$\,kPa（400\,mmHg）——两型号同此约束} \\
    \bottomrule
  \end{tabular}
\end{table}

\begin{figure}[htbp]
  \centering
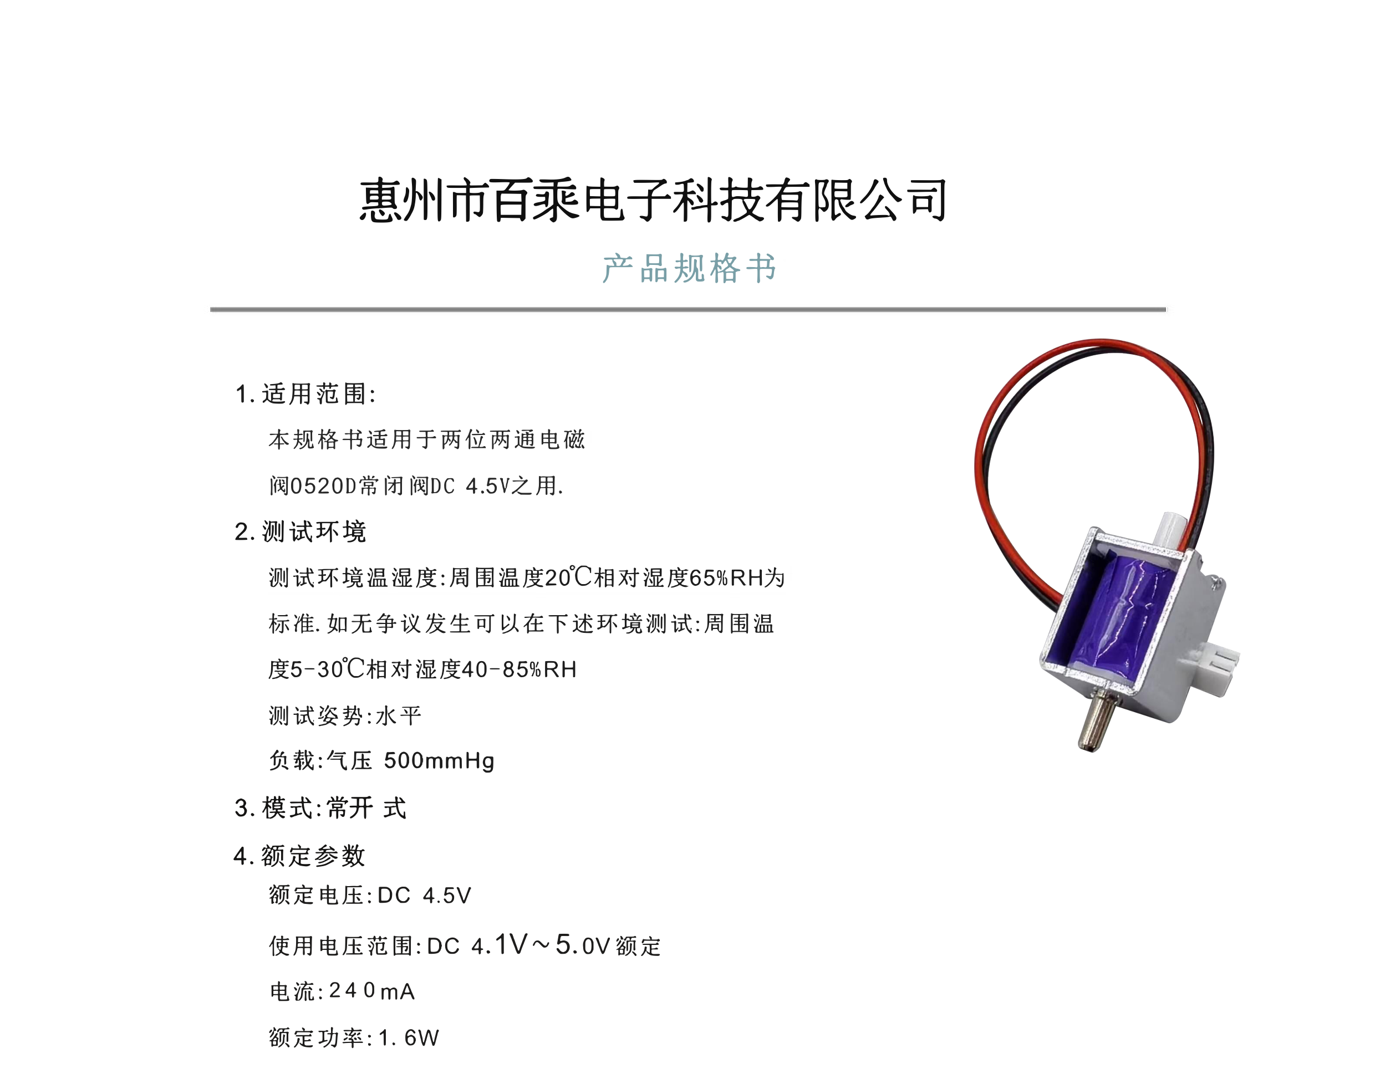
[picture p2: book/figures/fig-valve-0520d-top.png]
  
  \caption{0520D 常闭二通电磁阀实物（顶视，采购件翻拍；源图 \texttt{资源/实物图/valve0520d\_p1\_top.png}，16 张系列图存档同目录）}\label{fig:pneu-valve-d}
\end{figure}

\begin{figure}[htbp]
  \centering
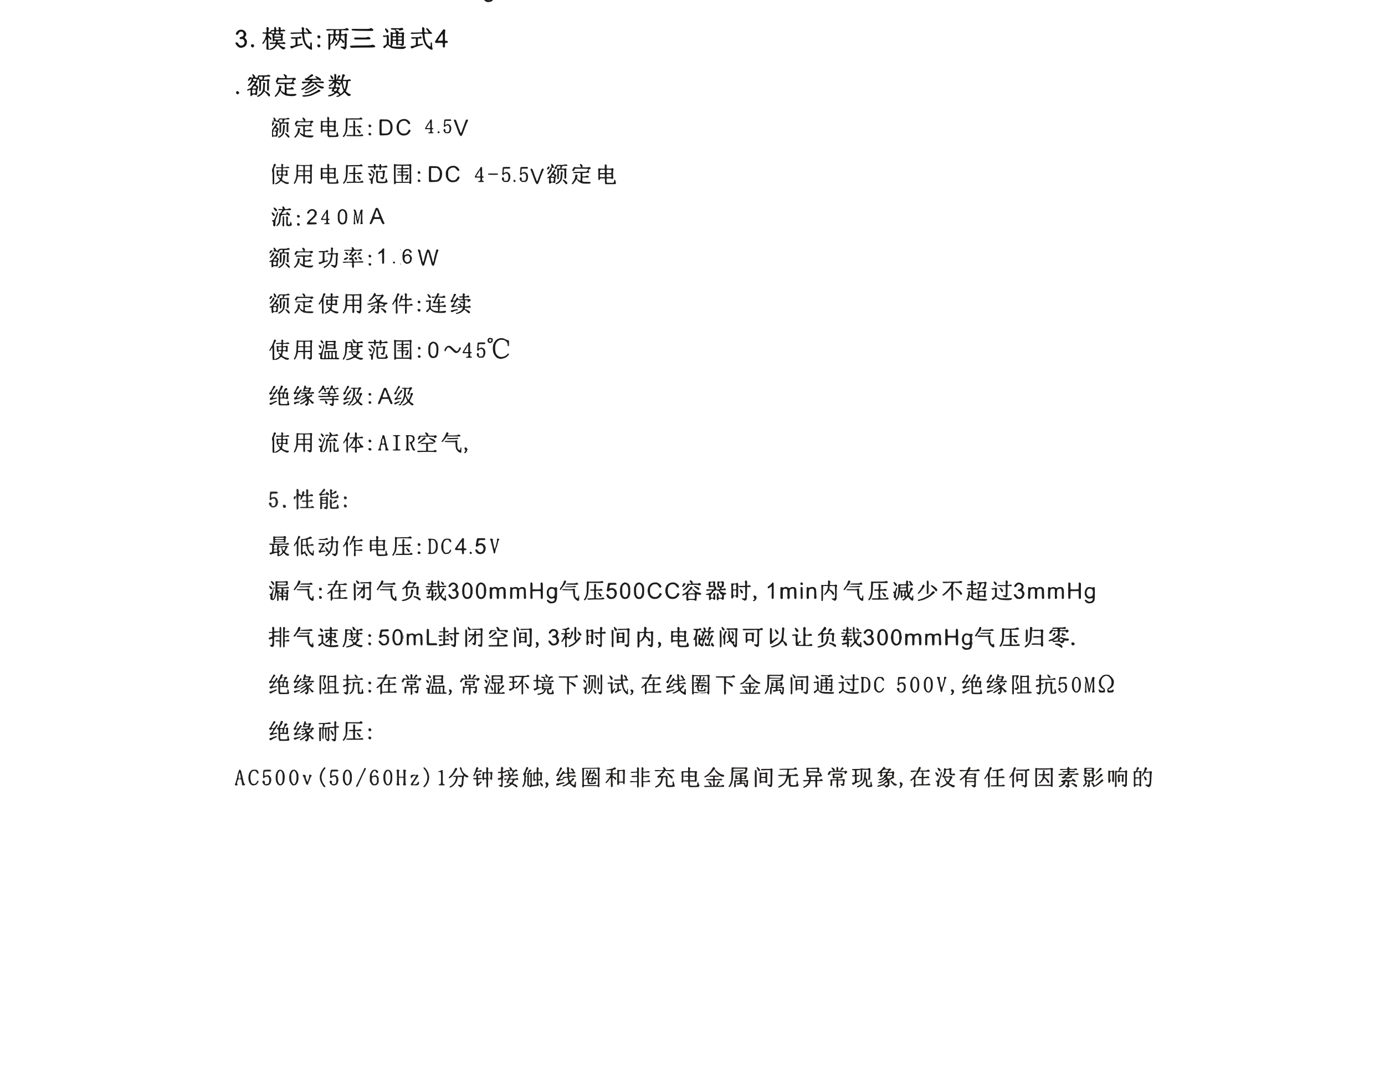
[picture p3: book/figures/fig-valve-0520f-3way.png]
  
  \caption{0520F 两位三通电磁阀实物（中段视角，三通结构可见；源图 \texttt{资源/实物图/valve0520f\_p1\_mid.png}）}\label{fig:pneu-valve-f}
\end{figure}

两份规格书里最有分量的数字是\textbf{动作压力下限 $-53.3$\,kPa}：阀在这个深度以下不能可靠通电切换。它反过来裁决了整机可用真空——泵规格书的极限是 $-58$\,kPa，但闭环"关阀保压"若在 $-53.3$\,kPa 以下触发就会失败，系统真空渐近值因此取链路最弱环节 $\max(-58,\,-53.3)=-53.3$\,kPa，并作为孪生参数表的定稿值（第~\ref{ch:twin} 章）。文献出处课与工程参数表在这里会师：一条规格书条款，穿过建模层，最终落成闭环策略的边界条件。

压力量程的实物印证来自另一颗采购器件：XGZP6897D-C 表压系列的量程分档覆盖 $-100\sim+200$\,kPa、I\textsuperscript{2}C 数字输出（手册 V1.1 首页）~\cite{xgzp6897d-v11}，孪生的 $\pm100$\,kPa 钳位取的正是其真空侧满量程；同系列 V2.5 版数据手册一并存档~\cite{xgzp6897d-v25}，第~\ref{ch:twin} 章驱动级三处修正对照的即此手册。

\begin{figure}[htbp]
  \centering
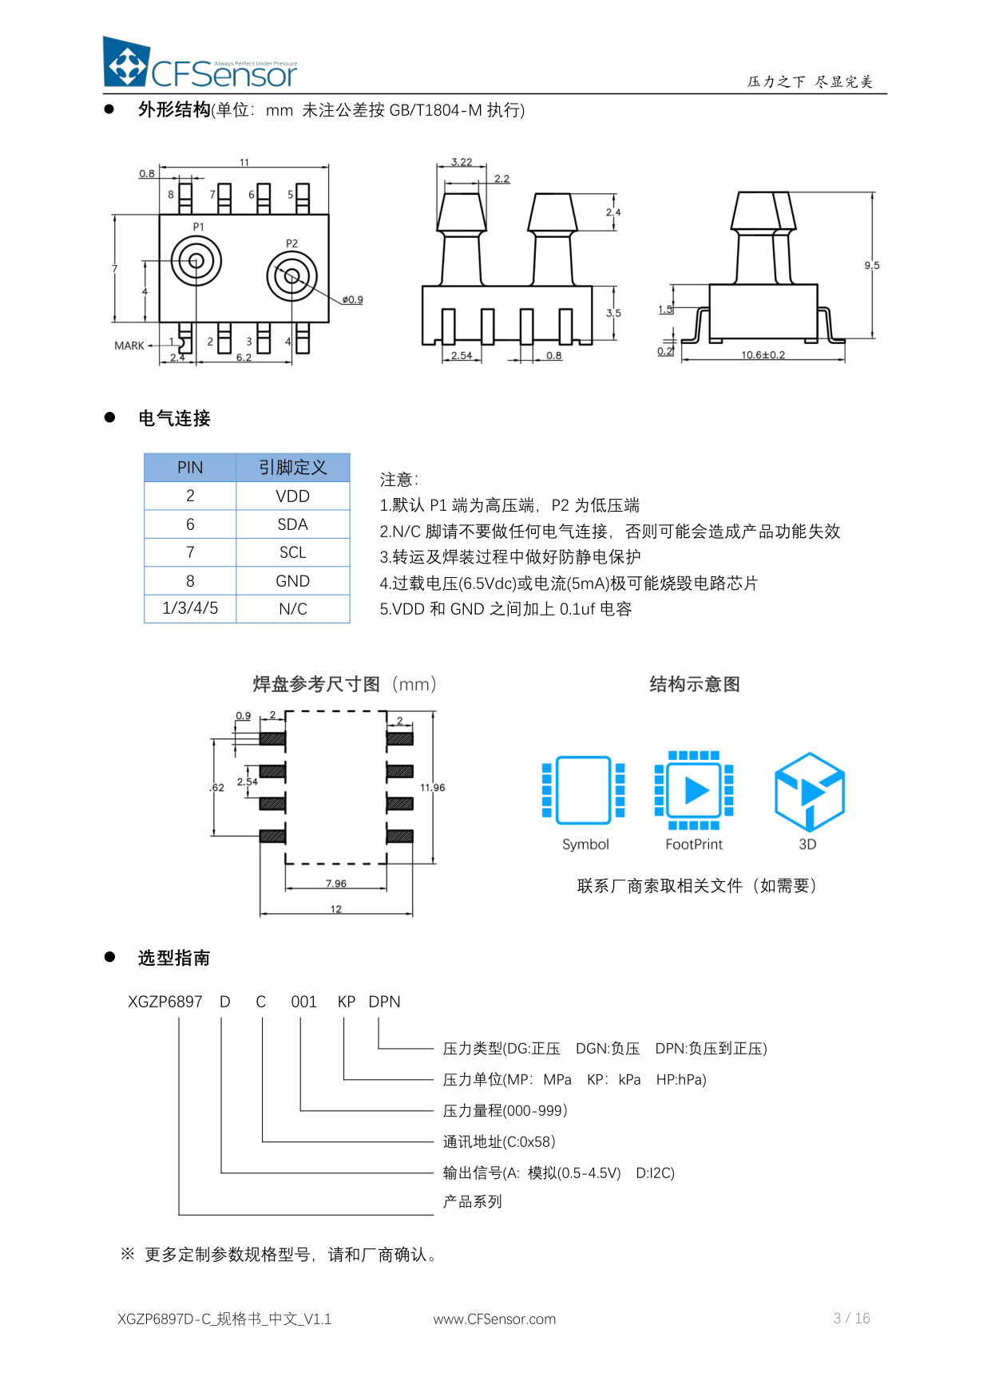
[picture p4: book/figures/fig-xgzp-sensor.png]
  
  \caption{XGZP6897D-C 压力传感器实物（SOIC8 封装；源图 \texttt{资源/实物图/xgzp\_p3.png}）——孪生 $\pm100$\,kPa 量程的器件来源}\label{fig:pneu-xgzp}
\end{figure}

\section{控制器谱系：从 PID 到模型基非线性}
\label{sec:pneu-control}

有了模型，控制器才能"看菜下饭"。Xavier 等 2022 年在 \emph{Frontiers in Robotics and AI} 的模型基非线性控制器研究~\cite{Xavier2022Frontiers} 把单阀系统的压力动力学整理为控制仿射形式 $\dot x = f(x) + g(x)u$（$x$ 为腔压、$u$ 为 40\,Hz PWM 占空比），并系统比较了谱系上的四档策略（表~\ref{tab:pneu-ctrl}）：实验整定的 PID/PI；状态依赖 Riccati 方程（SDRE）控制；滑模控制（SMC）与反馈线性化（FL）两支模型基非线性控制，以及为抗模型不确定性给二者附加的积分作用；最后是模型前馈 + 抗饱和 PI 的组合——用稳态占空比的前馈解 $u_{ff}$（令 $\dot x = 0$ 反解）抵消大部分非线性，PI 只收残差~\cite{Xavier2022Frontiers}。

\begin{table}[htbp]
  \centering
  \caption{气动软体执行器压力控制器谱系（据 \cite{Xavier2022Frontiers} 整理）}
  \label{tab:pneu-ctrl}
  \begin{tabular}{lp{3.2cm}p{3.4cm}p{2.2cm}}
    \toprule
    档位 & 策略 & 特征 & 本书采用 \\
    \midrule
    经典 & PID/PI + 抗饱和 & 免模型、整定靠实验 & \textbf{采用}：pn\_core 分指闭环（第~\ref{ch:firmware} 章） \\
    前馈增强 & $u_{ff}$ + PI & 模型抵扣非线性，PI 收残差 & 候选特性（泵 PID 连续流量同类思路） \\
    模型基 & SDRE / SMC / FL & 需要可信模型与全状态 & 暂不引入：参数成色不足 \\
    学习型 & 持续学习/自适应 & 数据驱动，样本昂贵 & 不引入（同第~\ref{ch:dt-theory} 章裁决） \\
    \bottomrule
  \end{tabular}
\end{table}

本书的选择是谱系的"保守端"：在阀线圈与泵参数仍是手册值（黄徽章）的阶段，模型基控制器的精度承诺兑现不了，PI + 抗饱和反而是\textbf{成色最诚实}的选择——这与第~\ref{ch:dt-theory} 章"按服务倒推技术"的原则一致：等孪生对拍把参数洗成实测值，前馈增强才有立足之地。

\section{交互装置脉络：PneUI $\to$ OmniFiber $\to$ FlowIO}
\label{sec:pneu-devices}

理论之外，本书的另一条血脉是 MIT 媒体实验室的交互装置谱系。2013 年的 PneUI~\cite{Yao2013} 把"气动驱动 + 多层软复合材料"引入界面：复合材料同时集成输入传感与形变输出，会变形的手机、可变高度的实体图标（phicon）、可变身平板套与变形台灯四个应用，确立了"压力 $\to$ 形变"作为\textbf{可编程物质}的交互原语~\cite{Yao2013}。执行器形态此后持续演化：2021 年的 OmniFiber~\cite{Afsar2021} 把流体驱动做进细径纤维——外径毫米级的薄壁纤维内嵌流体通道，可编织、可缠绕，钢琴教学辅具、呼吸感知胸衣、动力首饰等应用展示了"驱动器即材料"的可能性；其驱动硬件正是 FlowIO（合作者含 Shtarbanov）~\cite{Afsar2021}。

执行器越千变万化，驱动器越需要标准化——这是 FlowIO 的诞生逻辑。Shtarbanov 2021 年的 CHI 论文~\cite{Shtarbanov2021} 把它做成五端口、模块化（S/M/L 泵模块磁吸互换）、全集成（泵阀传感电池一体，主模块 77\,g）、带完整软件栈（Arduino/JavaScript/Web GUI）的可穿戴气动开发平台，"软体机器人的树莓派"；其 2025 年博士论文~\cite{Shtarbanov2025} 补齐了各泵模块的实测锚点（Small 模块 $-38\sim+61$\,kPa、$\pm0.3$\,L/min）——这组数字后来成为本书孪生参数表的初值（第~\ref{ch:twin} 章）。FlowIO 的动作语义（充气/抽真空/泄放/保压/测压/流量可变）与 PWM 调流量经验律~\cite{Shtarbanov2021}，被 FLOWIO-CN 的 CLI 动词与孔口乘子逐条继承（第~\ref{ch:intro} 章对照表）。

\section{康复手套前沿：便携拇指手套与织物综述}
\label{sec:pneu-rehab}

本书目标市场的两条最新文献边界，勾勒出"学术前沿走到哪、空白在哪"。Xie 等 2026 年发表于 \emph{Advanced Science} 的便携式软体手套~\cite{Xie2026} 是拇指全功能辅助的代表作：连续分段双腔折纸（origami）拇指执行器覆盖腕掌外展/内收、屈伸与指间伸展全部功能范围，指尖力 18\,N（约为克服典型中风痉挛所需的两倍）；系统集成传感化的便携驱动与"按需辅助"（assist-as-needed）控制器，三名慢性期卒中受试者完成捏取、侧捏、绕环、滑屏、拧盖与拇指对掌全部任务，侧捏力提升 62.9\%、拇指活动范围扩大九倍~\cite{Xie2026}。它验证了三件事：\textbf{拇指通道必须全功能}（与本书分指/分腔路线互证）、\textbf{驱动必须便携且带传感}（开环不可接受）、国产压力传感器（XGZP 同族）已进入顶刊方案。

Yilmaz 等 2026 年在 \emph{Advanced Materials Technologies} 的织物外骨骼手套综述~\cite{Yilmaz2026} 则盘点行业现状：制造家族、驱动机制、传感集成、控制架构与能源五个维度的进展与短板，并直指两个空白——\textbf{开环控制对康复手套根本不够}，以及\textbf{行业缺乏统一测试标准}~\cite{Yilmaz2026}。前者是本书"分指压力闭环一等公民"的文献判词，后者是"孪生对拍精度报告 + 36 张验收工单"的市场机会（第~\ref{ch:product}、\ref{ch:acceptance} 章）。

\section{本书定位：在谱系坐标上}
\label{sec:pneu-position}

把本章三段谱系放进同一张表（表~\ref{tab:pneu-position}），FLOWIO-CN 的位置一目了然：它不做执行器（织物与折纸气囊留给白牌厂商的传统强项），不做新材料驱动（SMA/纤维/DE 均非本书战场），而是把气动路线的\textbf{驱动与控制层}做成 B2B 产品——以本章三条方程为孪生物理，以谱系保守端的 PI 闭环为分指节拍，以 FlowIO 的语义为兼容接口，以两篇 2026 综述指出的空白（闭环、标准）为差异化卖点。

\begin{table}[htbp]
  \centering
  \caption{本书与本章文献谱系的定位对照}
  \label{tab:pneu-position}
  \begin{tabular}{lp{3.6cm}p{3.2cm}}
    \toprule
    工作 & 定位 & 与 FLOWIO-CN 的关系 \\
    \midrule
    PneUI~\cite{Yao2013} / OmniFiber~\cite{Afsar2021} & 交互原语 / 驱动材料 & 需求来源：执行器谱系越丰富，标准驱动器越稀缺 \\
    FlowIO~\cite{Shtarbanov2021,Shtarbanov2025} & 可穿戴开发平台 & 对标本体：语义与参数锚点的直接来源 \\
    Xavier 系列~\cite{Xavier2020AIM,Xavier2022Frontiers} / Stanley~\cite{Stanley2021} & 建模与控制方法 & 孪生物理 v2 的方程供应链 \\
    Xie 2026~\cite{Xie2026} & 顶刊拇指手套 & 路线互证：分指/传感/便携三项一致 \\
    Yilmaz 2026~\cite{Yilmaz2026} & 行业综述 & 空白判词：闭环与测试标准即卖点 \\
    \textbf{本书（FLOWIO-CN）} & 分指压力闭环 B2B 驱动套件 & 以上文献的工程收口 \\
    \bottomrule
  \end{tabular}
\end{table}

\section*{本章小结}
气动在软体驱动谱系中以"快响应、高力量重量比、执行器即气囊"胜出，其代价——一套泵阀传感系统——正是本书的产品本体~\cite{Xavier2022Frontiers,Sansone2022}。系统建模有三条公共方程：多变定律式~\eqref{eq:pneu-dpdt}（$\gamma{=}1.2$）、ANSI 孔口式~\eqref{eq:pneu-ansi}（含音速阻塞分支）与 RC 类化式~\eqref{eq:pneu-rc}~\cite{Xavier2020AIM,Xavier2022Frontiers,Stanley2021}；落到选型，0520D/0520F 规格书给出常闭二通与两位三通的国产现货对照，动作压力下限 $-53.3$\,kPa 裁决系统可用真空~\cite{valve-0520d-ds,valve-0520f-ds}，XGZP6897D 的量程分档实证了孪生的 $\pm100$\,kPa 钳位~\cite{xgzp6897d-v11}。控制器谱系从实验整定 PI 到模型基非线性依次升高，本书按参数成色选保守端~\cite{Xavier2022Frontiers}。装置脉络 PneUI$\to$OmniFiber$\to$FlowIO 证明驱动器标准化是执行器多样性的必然反题~\cite{Yao2013,Afsar2021,Shtarbanov2021}；康复前沿的拇指手套与织物综述则把"分指闭环 + 测试标准"标成行业空白~\cite{Xie2026,Yilmaz2026}。下一章开始，这些坐标全部变成工程图纸。

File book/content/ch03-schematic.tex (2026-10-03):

\chapter{原理图：从拓扑到 13 次修正}
\label{ch:schematic}

本章记录 FLOWIO-CN P1 主控板原理图的诞生过程。原理图不是一次画成的：它经历了 13 次编号修正（总表见~\ref{sec:sch-fixlog} 节），其中三次——电源或门二极管、Buck 反馈电阻、USB 转串口芯片——任何一次漏掉都会让整板无法工作或无法烧录。本章将这三个案例按"症状~$\to$~根因~$\to$~修法"完整复盘，并给出可 grep 的源码锚点。全部修正的权威记录见规格书 \texttt{docs/superpowers/specs/2026-10-01-flowio-p1-pcb-design.md} \S 9。

\section{设计基线：80\% 继承与总体拓扑}
\label{sec:sch-baseline}

原理图以 ESP32-S3-DevKitC-1 官方原理图为 baseline~\cite{ESP32S3DS,devkitc1-sch}：模组连接、EN 复位电路（RC+按钮）、strapping 偏置、自动下载（SS8050$\times$2）、USB 差分对与 ESD 全部继承，约占 80\%；FLOWIO-CN 特有的 8 路 AO3400 阀驱动~\cite{ao3400a-ds}、TCA9548A 五通道 I2C、五路 XH2.54 传感器座~\cite{xh254-ds}、WS2812B 状态灯与 12 个测试焊盘为新增。

电源拓扑（修正后）如下：DC-005 座（5V/3A）~\cite{dc005-ds}与 USB-C VBUS 各经一颗肖特基二极管做 Diode-OR 汇入 5V 共用轨；5V 轨经 TPS54331DR Buck（功率电感 6.8\,\textmu H CDRH103RNP~\cite{cdrh103rnp-ds}）降至 3.3V/3A，供 ESP32-S3、TCA9548A、CH340K、WS2812B 与五路传感器；8 路 AO3400A 直接驱动 7 阀 + 1 泵。阀 GPIO 分配为 4/5/6/7/10/11/12/21，I2C 主总线在 GPIO8/9（各 4.7\,k$\Omega$ 上拉），WS2812B 在 GPIO48。

\section{对照参考设计：与 DevKitC-1 的三处分野}
\label{sec:sch-devkit}

"以官方原理图为 baseline"不是抽象口号——把两份原理图摊开（图~\ref{fig:sch-devkit}），继承与分野一目了然。图示为 DevKitC-1 V1.1 官方原理图的电路页：CP2102N 下载桥、双 micro-USB 的二极管或门、SGM2212 LDO 与双 L8050 自动下载真值表全部在此页。逐网络对照后，真正被重新裁决的是三处（表~\ref{tab:sch-devkit}），每处都源于同一个身份差：DevKitC-1 是\textbf{逻辑级功耗的评估板}，P1 是\textbf{带 8 路执行器驱动的产品板}。

\begin{figure}[htbp]
  \centering
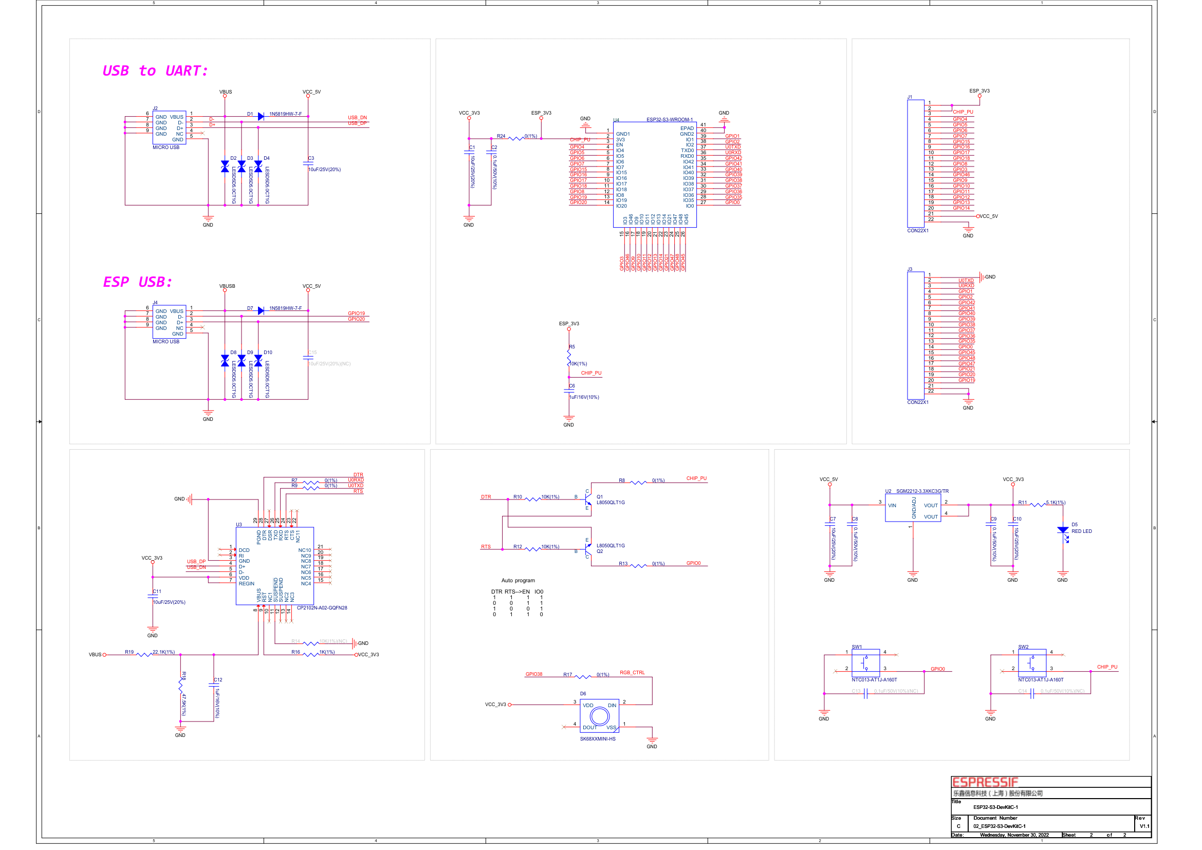
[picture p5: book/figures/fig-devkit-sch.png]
  
  \caption{ESP32-S3-DevKitC-1 V1.1 官方原理图电路页（图纸日期 2022-11-30~\cite{devkitc1-sch}；图源：官方 SCH PDF 转档 PNG，\texttt{资源/器件规格书/数据手册/devkitc1\_p2.png}）}\label{fig:sch-devkit}
\end{figure}

\begin{table}[htbp]
  \centering
  \caption{DevKitC-1 参考设计与 FLOWIO-CN P1 的三处对照（官方侧数据读自其原理图~\cite{devkitc1-sch}）}
  \label{tab:sch-devkit}
  \begin{tabular}{lp{4.4cm}p{4.6cm}}
    \toprule
    对照点 & DevKitC-1 V1.1（官方参考） & FLOWIO-CN P1（本书） \\
    \midrule
    复位与 strapping & CHIP\_PU 的 10\,k$\Omega$+1\,\textmu F RC、EN/BOOT 双按键；CP2102N 经双 L8050 的 DTR/RTS 自动下载真值表 & 拓扑全继承：双 SS8050 同一真值表（经 CH340K 的 DTR\#/RTS\#）；另补显式 strapping 偏置 $\times$4（GPIO0/3/45/46，修正 \#4）——评估板可吃模组默认态，产品板必须自己表态 \\
    电源 & 双 micro-USB 各经 1N5819（1A）二极管或门汇入 VCC\_5V；SGM2212-3.3 LDO 降至逻辑级 & 或门拓扑继承但二极管升 SS34（3A，修正 \#9）——5V 轨要喂 8 路执行器峰值 $>$2A；3.3V 改 TPS54331 Buck 3A，LDO 在该电流下压降功耗不可行 \\
    USB 通路 & 双 USB 座：CP2102N 下载桥 + GPIO19/20 原生 USB-OTG，各配 LESD5D5.0CT1G ESD & 单 USB-C（6P，CC 双 5.1\,k$\Omega$ 下拉）经 CH340K~\cite{ch340n-ds}（案例三：为 DTR\#/RTS\# 三次换型）+ USBLC6 ESD；USB 差分对走向与 ESD 位置继承 \\
    \bottomrule
  \end{tabular}
\end{table}

三处分野的共同逻辑值得写进方法论：\textbf{继承契约，升级路径}。下载真值表、ESD 防护、strapping 语义这类"与芯片厂商承诺绑定"的契约原样继承（改动即引入不可见风险）；电源与驱动这类"与负载绑定"的路径按产品预算重算（沿用才是风险）。它与 \S\ref{sec:sch-method} 的 51 核心板交叉检查互为镜像：前者向上对照官方参考设计防"画错"，后者向侧对照已知可用板防"漏画"。

\section{原理图即代码：gen\_sch.py 与程序化校验}
\label{sec:sch-gensch}

整张原理图由 \texttt{hardware/flowio-p1/tools/gen\_sch.py} 程序化生成：135 个器件、101 个网络、344 个连接全部写成数据结构，经程序化校验后导出 KiCad 工程与 PDF，ERC 零错误（commit \texttt{086e789}）。这带来一个关键性质：\textbf{修正是可 diff 的}。每颗器件的 LCSC 编码、封装与引脚-网络映射都是一行代码，本章三个案例都能用一行 grep 定位到修正后的现场：

\begin{itemize}
  \item Diode-OR：\texttt{grep "SS34\_C8678" gen\_sch.py} $\to$ L215--L228（D1/D2）与 L245--L246（Buck 续流 D3）；
  \item Buck 反馈：\texttt{grep "R324K" gen\_sch.py} $\to$ L249（R5 下分压电阻）；
  \item CH340K：\texttt{grep "CH340K" gen\_sch.py} $\to$ L263--L266（U4 引脚-网络映射）。
\end{itemize}

\section{三个真实修正案例：症状、根因与修法}
\label{sec:sch-cases}

\subsection{案例一（修正 \#9）：Diode-OR 的二极管——1A 器件扛 2A 电流}
\label{sec:sch-case9}

\textbf{症状。}初版双输入或门（DC 座与 USB-C 各一颗 1N5819W，1A/40V 肖特基）在纸面上成立：两路 5V 各自隔离、互不倒灌。但做电流预算复核时发现，5V 共用轨的下游是 8 路执行器——泵与多阀同时工作的峰值电流超过 2\,A，而无论从哪一路输入，全部电流都要流经那颗 1A 额定的二极管。若未修正，回板后的表现将是二极管压降异常增大、严重发热，长时间满载运行有烧毁风险——一块"原理上能跑"的板子藏在一条超载的电源路径。

\textbf{根因。}选型凭习惯拿了信号级的 1N5819W（1A，SOD-123），没有对电源路径做峰值电流预算。这是典型的"拓扑正确、参数错误"：Diode-OR 结构本身没有问题，问题是流过它的电流。

\textbf{修法。}或门两颗二极管升级为 SS34（3A/40V，SMA 封装，C8678），与 Buck 续流管（D3）统一物料；阀路续流仍用 SS14（1A）——修正 \#8 已把两类续流管的电流等级区分开。修法落在 \texttt{gen\_sch.py} L215--L228：D1（L219）接 DC\_IN $\to$ +5V，D2（L222）接 USB\_VBUS $\to$ +5V，均标注 \texttt{SS34\_C8678}。

\subsection{案例二（修正 \#11）：Buck 反馈电阻——2.33V 的"3.3V 轨"}
\label{sec:sch-case11}

\textbf{症状。}TPS54331 的输出电压由反馈分压决定：$V_\text{out} = V_\text{ref}\times(1+R_\text{上}/R_\text{下})$，其中 $V_\text{ref}=0.8$\,V。初版取 $R_\text{上}=10$\,k$\Omega$、$R_\text{下}=5.23$\,k$\Omega$（E96 顺手取值），代入得 $V_\text{out}=0.8\times(1+10/5.23)\approx2.33$\,V——一颗电阻选错，3.3V 轨实际只有 2.33V。ESP32-S3 的供电范围为 3.0--3.6\,V：回板后模组根本不会启动，表现是"电源灯亮、串口无横幅"，属于最难盲查的一类故障（一切看起来都通电了）。

\textbf{根因。}下分压电阻按 E96 序列顺手取值，取完没有代回分压方程验算。电源芯片的外围参数不能靠"阻值常见"来选，必须算。

\textbf{修法。}$R_\text{下}$ 改 3.24\,k$\Omega$、1\% 精度：$V_\text{out}=0.8\times(1+10/3.24)\approx3.27$\,V，落在 3.3V$\pm$3\% 的窗口内。修法落在 \texttt{gen\_sch.py} L248--L249：R4（10\,k$\Omega$，+3V3 $\to$ FB）与 R5（\texttt{R324K}，FB $\to$ GND）构成分压。这个案例后来直接进入了回板验收工单 A201"首电三测"的期望值：5V$\pm$5\%、3.3V$\pm$3\%。

\subsection{案例三（修正 \#10+\#12）：USB 转串口芯片三次换型——CH340N$\to$E$\to$K}
\label{sec:sch-case12}

\textbf{症状。}自动下载电路需要转串口芯片同时引出 DTR\# 与 RTS\# 两根握手线（经 1\,k$\Omega$ 驱动两颗 SS8050，分别拉 EN 与 GPIO0，这是 esptool \texttt{default\_reset} 进下载模式的前提）。初选 CH340N：封装里没有 DTR\# 引脚，自动下载电路无从谈起——每次烧录都要手按 BOOT。于是修正 \#10 换成 CH340E：内置振荡器还省掉了 12\,MHz 晶振与两颗负载电容。但核对官方文档 CH340DS1 v3B 的引脚表后发现：\textbf{CH340E 同样没有 DTR\#}。若到此为止，回板后将得到一块"能打印日志、但不能自动烧录"的板子。

\textbf{根因。}两次选型都依赖社区记忆而非官方引脚表——"CH340 系列应该有 DTR"是一个想当然。引脚级的契约（哪个封装的哪个脚是 DTR\#/RTS\#）必须以厂商文档为准。

\textbf{修法。}换 CH340K（ESSOP-10，C968586）：官方引脚表确认 pin4=DTR\#、pin6=RTS\#，且内置振荡器。修法落在 \texttt{gen\_sch.py} L255--L284：U4 引脚-网络映射（L263--L266）中 \texttt{"4": "DTR", "6": "RTS"}，经 R19/R20（1\,k$\Omega$）与 R21/R22（10\,k$\Omega$ 上拉）驱动 Q11/Q12 两颗 SS8050（L276--L283）完成自动下载。另按修正 \#2，CH340K 从 3.3V 轨供电且 V3 短接 VCC（3.3V 模式），从根上消除 USB 5V 向 3.3V 轨的倒灌路径。

\section{13 次修正总表}
\label{sec:sch-fixlog}

\begin{table}[htbp]
  \centering
  \caption{原理图阶段 13 次编号修正（spec \S 9 修正记录摘编）}
  \label{tab:sch-fixes}
  \begin{tabular}{clp{8.2cm}}
    \toprule
    \# & 修正 & 原因 \\
    \midrule
    1 & 电源从双轨改单轨 & 过度复杂；消除 CH340N 倒灌路径 \\
    2 & CH340N 从 3.3V 供电 & 手册 p9 倒灌防护；简化 \\
    3 & 新增 I2C 上拉 $\times$12 & 51 核心板交叉检查发现遗漏 \\
    4 & 新增 strapping $\times$4 & 51 核心板交叉检查发现遗漏 \\
    5 & 新增 SS8050 外围 $\times$4 & 深度审查发现遗漏 \\
    6 & 新增 WS2812B 外围 $\times$2 & 深度审查发现遗漏 \\
    7 & 电源开关改为无开关 & SS-3235S 的 50mA 额定不够 3A \\
    8 & SS14 与 SS34 区分使用 & 阀续流 1A 与 Buck 续流 3A 电流等级不同 \\
    9 & Diode-OR 改 SS34 & 5V 轨承载泵+阀峰值大于 2A，1N5819W 的 1A 额定不足 \\
    10 & CH340N$\to$CH340E & N 无 DTR\# 无法自动下载；E 内置振荡器省晶振 \\
    11 & 反馈电阻 5.23k$\to$3.24k & 5.23k 只得 2.33V；3.24k 得 3.27V \\
    12 & CH340E$\to$CH340K & 官方引脚表核对：E 无 DTR\#，K 有 DTR\#(4)+RTS\#(6) \\
    13 & 板尺寸 80$\times$70$\to$90$\times$75 & 17 个连接器在 80$\times$70 饱和；8 端子单排需 $\ge$88\,mm \\
    \bottomrule
  \end{tabular}
\end{table}

\section{修正从哪里来：三层交叉检查}
\label{sec:sch-method}

复盘 13 次修正的来源，可以归纳出三层互补的检查网：其一，\textbf{对照检查}——拿一块已知可用的核心板（51 板）逐网络比对，补出 I2C 上拉与 strapping（\#3/\#4）；其二，\textbf{参数验算}——对每条电源路径做电流预算、对每个分压/补偿网络代回公式（\#7/\#9/\#11）；其三，\textbf{官方文档核对}——引脚级契约以数据手册为准（\#10/\#12，CH340DS1 v3B）。三层缺一不可：第一层抓"漏画"，第二层抓"画错"，第三层抓"想当然"。

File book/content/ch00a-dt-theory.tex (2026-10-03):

\chapter{数字孪生：从概念到工程}
\label{ch:dt-theory}

本书的孪生先行章（第~\ref{ch:twin} 章）会让固件在真板回来之前就跑在一套气动微分方程上；孪生前端章（第~\ref{ch:host} 章）的 Web 页面会以"孪生/真机"两种徽章渲染同一份遥测。这些工程实践并不是凭空发明——它们站在一个已有二十余年积累的方法论之上：\textbf{数字孪生}（digital twin, DT）。本章把这条理论线索讲清楚：数字孪生从哪里来、它的五维模型是什么、靠哪些技术栈落地、在机器人领域已经走到哪一步。理论篇的使命只有一个——让后面十章的每一条孪生决策都能向上追溯到一个被反复引用过的框架，而不是"别人都这么做"。

\section{概念与演化：从 PLM 构想到工业互联网基石}
\label{sec:dt-history}

数字孪生的思想源头通常追溯到 2003 年前后 Grieves 在密歇根大学产品全生命周期管理（PLM）课程中提出的"镜像空间模型"：一个产品系统应当同时包含\textbf{物理空间}的实体、\textbf{虚拟空间}的数字化模型，以及连接两者的\textbf{信息接口}——三要素构成的闭环，是此后一切数字孪生定义的雏形。2010 年代初，NASA 在飞行器健康管理的技术路线图中采用 digital twin 一词，用它描述"与单个飞行器全生命周期对应的集成多物理、多尺度、概率性仿真模型"，概念由此从课堂构想进入工程语境；工业互联网与工业 4.0 浪潮随后把它推成了智能制造的核心关键词之一。

对这段历史与工业落地现状最系统的整理，是陶飞团队 2019 年发表于 IEEE TII 的综述 \emph{Digital Twin in Industry: State-of-the-Art}~\cite{Tao2019}。这篇综述在 2026 年 10 月经 AMiner 检索已被引用逾 4600 次，是中文世界被引最高的数字孪生文献之一；它把概念提出到成文的时间差概括为"约十五年"，并把工业应用归纳为产品设计、生产制造、故障预测与健康管理（PHM）等若干大类，同时列出数据、建模、标准三个层面的挑战。对本书而言，这篇综述的价值有三：其一，它确认了"虚拟-物理无缝集成"是数字孪生的定义性特征，而非附加属性；其二，它把 PHM（预测性健康管理）列为一级应用方向——本书验收篇（第~\ref{ch:acceptance} 章）的泄漏诊断与孪生对拍精度报告，本质上就是驱动板这一"产品"的 PHM 缩影；其三，它指出的挑战（模型可信度、数据质量、标准缺位）恰好对应本书第~\ref{ch:twin} 章"参数成色四档"与第~\ref{ch:product} 章"精度报告"要解决的问题——理论界的挑战清单，就是工程书的目录。

概念演化见表~\ref{tab:dt-history}。

\begin{table}[htbp]
  \centering
  \caption{数字孪生概念演化脉络（据 \cite{Tao2019} 综述整理）}
  \label{tab:dt-history}
  \begin{tabular}{lp{5.0cm}p{4.6cm}}
    \toprule
    时期 & 事件 & 对本书的含义 \\
    \midrule
    2003 前后 & Grieves 于 PLM 课程提出镜像空间模型：物理/虚拟/连接三要素 & 孪生的最小定义，即"模型 + 实体 + 闭环" \\
    2010 年代初 & NASA 路线图采用 digital twin 描述飞行器健康管理 & PHM 成为一级应用，对应验收篇对拍与泄漏诊断 \\
    2015--2019 & 工业 4.0/工业互联网把 DT 推为智能制造使能技术 & B2B 客户对"孪生"有认知，数据报表有市场 \\
    2019 至今 & 工业综述~\cite{Tao2019}、建模方法论~\cite{Tao2022}、使能技术盘点~\cite{Qi2021} 相继成体系 & 本书孪生架构的理论锚点（本章 \S\ref{sec:dt-5d}--\S\ref{sec:dt-stack}） \\
    \bottomrule
  \end{tabular}
\end{table}

\section{五维模型：给"孪生"一个可检查的骨架}
\label{sec:dt-5d}

概念会通胀，结构不会。数字孪生领域最经得起引用的结构化表述，是陶飞学派提出的\textbf{五维模型}：物理实体（physical entity, PE）、虚拟实体（virtual entity, VE）、服务（services, Ss）、孪生数据（twin data, DD）与连接（connection, CN）五者互联~\cite{Qi2021}。它把早期三要素扩展为工程可检查的清单——一个声称"有数字孪生"的系统，应当能逐维回答"你的 PE 是什么、VE 在哪、数据流是什么、提供什么服务、靠什么连接"。

五维各自的内涵，在陶飞团队 2022 年的 \emph{Digital Twin Modeling}~\cite{Tao2022} 中得到系统化：该文从应用领域、层级、学科、维度、普适性、功能性六个视角剖析现有孪生模型，再按建模理论体系归纳六个建模方面，并盘点配套的使能技术与工具。对建模者最重要的论断是：\textbf{孪生建模是数字孪生准确刻画物理实体的核心}，孪生的功能服务能否兑现，取决于模型成色~\cite{Tao2022}。这句话在本书将被反复验证——第~\ref{ch:twin} 章的物理 v2 重构（每条规律给出文献出处）、参数成色四档（实测 $>$ 手册 $>$ 仿真 $>$ 假设），正是"模型成色决定服务成色"在一张 90$\times$75\,mm 驱动板上的落地。

把五维模型当作检查表套在 FLOWIO-CN 上，得到表~\ref{tab:dt-5d-map}——它也是理解全书结构的另一张地图。

\begin{table}[htbp]
  \centering
  \caption{五维模型 $\to$ FLOWIO-CN 孪生逐维映射}
  \label{tab:dt-5d-map}
  \begin{tabular}{lp{6.6cm}}
    \toprule
    维度 & FLOWIO-CN 中的实现（章） \\
    \midrule
    PE 物理实体 & P1 驱动板 + 五路执行器气路 + 泵阀传感（第~\ref{ch:schematic}、\ref{ch:pcb}、\ref{ch:fab} 章） \\
    VE 虚拟实体 & \texttt{twin\_api.c} 气动物理 + \texttt{board\_model.py} 电气 + 3D 装配模型（第~\ref{ch:twin}、\ref{ch:enclosure}、\ref{ch:host} 章） \\
    Ss 服务 & 闭环节拍、对拍精度报告、验收工单、数据报表（第~\ref{ch:firmware}、\ref{ch:acceptance}、\ref{ch:product} 章） \\
    DD 孪生数据 & 50\,ms 遥测流、600\,s 环形历史、CSV 对拍数据集（第~\ref{ch:twin}、\ref{ch:host} 章） \\
    CN 连接 & 串口 0xA5 协议、BLE GATT 四服务、HTTP API（第~\ref{ch:ble}、\ref{ch:sdk} 章） \\
    \bottomrule
  \end{tabular}
\end{table}

这张映射表还暴露了一个诚实的细节：五维的"成色"并不均一。PE 维是实测的（板在手），CN 维是契约化的（协议有测试），但 VE 维的若干参数（阀线圈电阻/电感、泵死点）在 BOM 锁定前仍是手册值或典型值——第~\ref{ch:twin} 章用徽章把它们显式标黄，而不是藏在演示数字后面。\textbf{把未标定的维度标成黄色}，是五维模型对单人项目最有用的一条工程化改造：它把"模型可信度"（\cite{Tao2019} 列出的领域级挑战）压缩成了一张人人可查的表。

\section{使能技术栈：建模、数据、通信、服务}
\label{sec:dt-stack}

五维是骨架，使能技术是血肉。齐庆林（Qi）等 2021 年发表于 \emph{Journal of Manufacturing Systems} 的 \emph{Enabling technologies and tools for digital twin}~\cite{Qi2021} 从五维视角盘点了高频使用的使能技术与工具，是引用逾千次的领域工具书式综述。按"建模/数据/通信/服务"四类归纳，技术栈与本书的对应关系见表~\ref{tab:dt-stack}。

\begin{table}[htbp]
  \centering
  \caption{数字孪生使能技术四类与本书选型（框架据 \cite{Qi2021}）}
  \label{tab:dt-stack}
  \begin{tabular}{lp{4.4cm}p{4.8cm}}
    \toprule
    类别 & 领域常用技术（综述概括） & FLOWIO-CN 选型 \\
    \midrule
    建模与仿真 & 几何/物理/行为/规则多层建模，多物理场仿真 & C 物理积分（多变定律 + 孔口）+ Python 电气模型 + STL 装配 \\
    感知与数据 & 多源传感、数据融合、实时数据库 & XGZP6897D 经 TCA9548A 分时采样（P0 实装 2 只：汇流管+端口侧，可扩 5 端口座）、50\,ms 遥测、环形历史 \\
    通信与连接 & 总线、无线、网络协议 & I2C/TCA9548A、UART 0xA5、BLE GATT、HTTP \\
    服务与应用 & 监控、仿真、预测、优化四类服务~\cite{Tao2022} & 遥测面板、时间缩放回放、泄漏诊断、闭环整定 \\
    \bottomrule
  \end{tabular}
\end{table}

值得强调的是综述里的一条隐含纪律：\textbf{技术选型应从维度需求出发，而不是从流行度出发}。五维中 DD 维的"实时性"决定连接技术的采样率与协议；Ss 维的"预测"才引入学习类方法。本书没有引入任何学习型组件——因为它的服务清单（闭环、对拍、报表）用物理模型加统计即可兑现；这条"按服务倒推技术"的路线，正是 \cite{Qi2021} 工具盘点方法论的逆序使用。

\section{机器人数字孪生：三个近年样本}
\label{sec:dt-robots}

数字孪生的工业叙事以飞机、产线、车间为主角；机器人是其中更年轻的分支。三个近年样本足以勾勒这条支线的现状（表~\ref{tab:dt-robots}）。

\textbf{样本一：持续学习抓取检测。}北航 Ren 等 2024 年发表于 IEEE TIE 的 \emph{Digital Twin Robotic System With Continuous Learning for Grasp Detection in Variable Scenes}~\cite{Ren2024} 构建了"数字孪生 + 持续学习"的机器人系统：孪生侧生成由工业零件构成的合成抓取检测数据集，物理侧在变化场景中抓取，新场景数据回流触发模型再训练——用孪生数据补真实数据的稀缺，用持续学习吸收场景漂移。这是"孪生数据（DD 维）直接喂养服务（Ss 维）"的完整示范。

\textbf{样本二：手术模拟器。}Cai 等 2023 年在 \emph{Bioengineering} 上实现的虚拟现实数字孪生微创手术模拟器~\cite{Cai2023}，把孪生用于技能训练而非监控：物理机器人执行操作，孪生侧渲染 VR 场景并评估操作质量。它提示孪生的 Ss 维不必是"看板"，也可以是\textbf{训练与评估环境}——本书孪生前端 v2 的"仿真实验室"浮层（第~\ref{ch:host} 章）与此同宗：把危险或昂贵的物理试验搬进可重放的数字副本。

\textbf{样本三：物理-虚拟机器人手。}Singh 与 Ray 2024 年在 IJIDeM 上提出物理-虚拟数字孪生机器人手~\cite{Singh2024}，让物理手与虚拟手双向映射、协同演示。它与本书的关系最近：手的分指动作在虚拟侧复现，正是康复手套数据报表的产品形态预演——白牌厂商的客户（康复科）最终看到的"疗程数据"，就是这类物理-虚拟映射的消费端。

\begin{table}[htbp]
  \centering
  \caption{机器人数字孪生三个样本与本书的对照}
  \label{tab:dt-robots}
  \begin{tabular}{lp{3.4cm}p{3.4cm}p{2.6cm}}
    \toprule
    工作 & 孪生的主要用途 & 与 FLOWIO-CN 的同构 & 差异 \\
    \midrule
    Ren 2024~\cite{Ren2024} & 合成数据 + 持续学习 & DD 维反哺服务 & 学习型组件本书暂不引入 \\
    Cai 2023~\cite{Cai2023} & VR 训练评估环境 & 仿真实验室浮层同宗 & 本书面向产品验收而非技能训练 \\
    Singh 2024~\cite{Singh2024} & 物理-虚拟双向映射 & 分指遥测的报表预演 & 本书映射对象是驱动板与气路 \\
    \bottomrule
  \end{tabular}
\end{table}

三个样本的共同点值得写成一句判词：机器人数字孪生的价值不在"复制出一模一样的几何"，而在\textbf{让数字副本承担物理系统做不起的试验}——数据稀缺时造数据（Ren），试验昂贵时当沙盘（Cai），展示不便时做镜像（Singh）。本书孪生承担的正是第三种之外的全部：回板前的固件沙盘（第~\ref{ch:firmware} 章 QEMU 冒烟）、协议调试的假硬件（第~\ref{ch:ble}、\ref{ch:sdk} 章）、出厂筛选的泄漏工况注入（第~\ref{ch:twin} 章）。

\section{本书路线图：理论如何兑现为十二章}
\label{sec:dt-roadmap}

本章的理论至此收束为三条可执行的原则，它们将在实践篇被逐条兑现：

\begin{itemize}
  \item \textbf{五维检查表}：任何自称孪生的模块，必须能回答 PE/VE/Ss/DD/CN 五问（表~\ref{tab:dt-5d-map}）。第~\ref{ch:twin} 章的孪生架构、第~\ref{ch:host} 章的前端信息架构，都按这张表自检。
  \item \textbf{模型成色分级}：孪生建模是核心，模型成色决定服务成色~\cite{Tao2022}；实测 $>$ 手册 $>$ 仿真 $>$ 假设的四档徽章（第~\ref{ch:twin} 章）是这条原则的操作化。
  \item \textbf{按服务倒推技术}：使能技术的取舍从 Ss 维服务清单出发~\cite{Qi2021}，不从流行度出发——这就是本书没有机器学习组件、却有 36 张验收工单的原因（第~\ref{ch:acceptance} 章）。
\end{itemize}

第~\ref{ch:intro} 章（生态位）回答"为什么做"，本章回答"用什么理论做"，第~\ref{ch:twin} 章开始回答"具体怎么做"。"十二章"指第~\ref{ch:intro} 章起的内容章（实践篇十章 + 验收与标定两章）；理论篇的本章与气动理论章不计入其中。第 II 部的十章实践，本质上就是把表~\ref{tab:dt-5d-map} 的五行逐行施工；第 III 部的验收与产品化，则是对 Ss 维（精度报告、数据报表）的最终交付。理论到此让位。

\section*{本章小结}
数字孪生从 Grieves 的三要素构想演化到工业互联网的基石~\cite{Tao2019}，其最有工程价值的结晶是五维模型~\cite{Qi2021}与"建模为核心"的方法论体系~\cite{Tao2022}；机器人分支的三个样本~\cite{Ren2024,Cai2023,Singh2024}展示了孪生在造数据、当沙盘、做镜像上的价值。本书把五维模型用作检查表、把模型成色用作徽章、把服务清单用作技术选型的倒推依据——理论不是装饰，是第~\ref{ch:twin} 章之后每一张图的坐标轴。

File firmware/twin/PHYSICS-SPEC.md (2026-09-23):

# PHYSICS-SPEC v2 — 孪生物理（文献驱动）

> 状态：**已批准实施**（2026-09-22，用户决策：随 TinyML Phase 0 泄漏注入一并落地）
> 前置：三篇核心文献已阅读（见 `../../literature/README.md`）
> 本版取代 v1（twin_api.c 现行一阶模型，提交 b6624cd）的"方向正确、形式简化"实现

## 1. 文献依据（逐条对应）

| 物理规律 | 文献出处 | 采用形式 |
|---|---|---|
| 气体状态与压力动力学 | Xavier 2022 §2.1 Eq.1-4 | 多变气体定律 PV^γ=const；**dP_A/dt = γ·P_A/V_A · Q_net**（γ=1.2，文献 §4 取值） |
| 阀孔流量 | Xavier 2022 §2.1 Eq.3（ANSI/(NFPA)T3.21.3 标准） | Q = 114.5·u·C_v·√(ΔP·P_low)/√T_high（L/s，绝对压 bar）；充气 Eq.5：Q_c ∝ √(P_A(P_R−P_A)) |
| 音速阻塞（choked flow） | ANSI 标准隐含（P_high/P_low > 1.893 时临界流） | 高压差段流量与 √ΔP 解耦（恒质量流）——v1 完全缺失的真实现象 |
| 占空比=流量标度 | Xavier 2022（40Hz PWM 阀）；FlowIO CHI'21 §4（泵 PWM 调流量） | u ∈ [0,1] 线性标度 ✓（v1 已实现，保留） |
| 常闭阀默认保压 / 被动释放 / 单向流动 | FlowIO CHI'21 §4 | ✓（pn_core 已实现，不变） |
| 单传感器分时测量 | FlowIO CHI'21 §4（汇流管传感器逐口分时；Sensors++ 才每口独立） | S0=汇流管探头定位依据；S1=端口侧探头（Sensors++ 雏形） |
| 规格包线 | FlowIO CHI'21：−26~+30 psi（≈−179~+207 kPa）、3.2 L/min（平台各模块包线） | P0 单泵模块远小于此；UI 曲线图按 ±100 kPa 传感器量程展示（不变） |

**v1 → v2 差异一览**（v1 为工程一阶近似，v2 换成文献形式）：

| 环节 | v1（现行） | v2（本 SPEC） | 文献依据 |
|---|---|---|---|
| 泵充压 | 线性压头 (1−p/P_max) | 孔口形式 √(p(P_R−p)) + choked 段 | Xavier Eq.5 + ANSI |
| 抽真空 | 对称线性 | 孔口形式 √(p(p−P_min)) + choked 段 | Xavier Eq.6 对称 |
| 被动排气 | 指数衰减 τ=1.6s | ANSI 孔口（含 choked 恒流段→√ 衰减尾）；管路段按 ASME 次要损失 ΔP=½Kρu²（Stanley & Amini 2020，用户补充文献） | Xavier Eq.6 + ASME RC |
| 容积 | 固定 | **V(n) = V_m + n·V_p**（开阀端口数改变压力速率）+ 开阀瞬时等温混合 | Xavier Eq.4 的 1/V；ASME 验证区间 0.5–16 mL 容积恰为 P0 汇流管+端口通道尺度（0.2–16 mL 量级互洽） |
| 微漏 | 比例 1%/s | 不变（密封面泄漏，文献外经验值，标注待标定） | — |

## 2. 模型定义（实现于 twin_api.c）

状态：p（汇流管表压 kPa）；端口阀开集 S；各阀 duty u。

每 tick（50ms，dt=0.05）：
```
P = p + 101.325（绝对压 kPa）→ 按 ANSI 单位换算 bar
V = V_m + |S|·V_p                       （L）
Q = 0
若 pump∧inlet：  Q += u_pump·C_pump·F(P, P_R)     F(x,y)=114.5·√(x(y−x))/√T   [sub-critical]
                                                        临界：x/y > 0.528 → 恒流支
若 pump∧vent(真空)：Q −= u_pump·C_pump·F(P_atm↔, P_min)   （对称，P<P_atm 时抽气）
若 vent∧¬pump：  Q −= C_vent·F_choked(P, P_atm)   （释放；P<P_atm 时反向回充）
dp = γ·(P)/V · Q · dt                    （γ=1.2）
端口阀 0→1 瞬间：p ← p·V_旧/V_新          （新通道为大气压，等温瞬时混合）
p 钳位 [−100, +100] kPa（XGZP6897D 量程饱和）
```

## 3. 参数表（标定计划）

| 参数 | 含义 | **实测值（实验校准）** | 校准依据 |
|---|---|---|---|
| P_R−P_atm | 泵充气滞止表压 | 61 kPa | FlowIO Small Pump Module 实测死点（thesis Table 2） |
| P_min−P_atm | **系统真空渐近** | **-53.3 kPa** | **= max(泵 -58, 阀动作窗 -53.3)**：泵极限 -58（370/FIT0801）；0520D/F 规格书动作压力下限 **-53.3 kPa**（`literature/valve-0520df-spec.md`，2026-09-23）——阀在 -53.3 以下不能可靠通电切换，是链路最弱环节。原 -38 为 FlowIO 借值、-58 为泵单独极限，均已过时 |
| C_pump (PUMP_C) | 泵路等效流导 | **9.0e-8** | 实验校准：2s→19kPa、渐近 61 死点（理论推导存在量纲差，以实测为准） |
| C_vent (VENT_C) | 排气阀路流导 | **1.0e-5** | **演示时间尺度假设**（40kPa→0 ~4s，无实物依据）：裸阀 Cv0.05(0520D)/0.10(0520F) 全开流导高约 2 个量级，实物排气显著更快——到货 calibrate_pump.py 重标 |
| C_leak (LEAK_C) | 泄漏单位流导 | **1.0e-5** | ML 数据工厂参数（k=0.2 → 26kPa 处降 3.15 kPa/s），非硬件值 |
| 密封微漏率 | SEAL_LEAK_PER_S | **0.01/s** | 好品假设 ≈3mL/min@40kPa·V5mL；手册上限 0520D/F 内漏 ≤30mL/min ≈0.073/s——接近上限的阀会被 ML 判泄漏（设计意图：内漏超标=废品该暴露） |
| 阀响应时间 | （未建模，瞬时） | — | 0520D ≤20ms / 0520F ≤30ms（规格书）<< 50ms tick，瞬时假设成立 |
| 阀孔径/Cv | （未单独建模） | — | 0520D Φ1.2mm/Cv0.05；0520F Φ1.5mm/Cv0.10——裸阀流导 >> 泵（2.2L/min），阀非充压瓶颈 |
| V_m / V_p | 汇流管/端口通道容积 | 5 mL / 2 mL | 结构设计值（待到货实测修正） |
| γ | 多变指数 | 1.2 | Xavier 2022 §4 |

> 论文备注：同型号泵存在个体性能差异（thesis p.120），标定需以到货实测为准；上表为官方 Small 模块锚点，若 P0 实际采用更接近 Medium 的泵（-61~+165 kPa），仅改两个宏即可。

## 4. 验证（更新 TEST-CASES §I）

- 充压曲线按 √ 压头形式拟合（非线性回归替代 v1 的渐近线性断言）
- 高压差段（>53 kPa 表压，P/P_atm>1.893 边界之上）识别 choked 恒流：释放初期降压速率近似恒定
- **容积耦合**：同 PWM 下开 1 口 vs 开 3 口充压，后者速率显著低（ΔV/V 断言）
- 开阀混合：密封 60 kPa 时开新端口 → 压力阶跃下降且按 V_m/(V_m+V_p) 可预测
- 真空/回充/微漏/量程饱和：沿用 v1 用例
- 自测程序 twin_selftest.c 期望值按 v2 重算

## 5. 实施计划（5 步，每步全量回归）

1. twin_api.c 实现孔口方程 + choked 分支（参数表初值），保留 γ·P/V 形式
2. 容积耦合与开阀混合（端口阀状态沿检测）
3. twin_selftest.c 期望值重算 + bash build_twin.sh 自测
4. test_api.sh §I 断言改 v2 形式（√ 拟合 / choked 段 / 容积耦合 3 用例）
5. run_tests.sh 全绿 → SPEC.md 补 v1.3 修订 → 提交

**待用户决策项**（沿用 v1 遗留）：超压保护阈值 120 kPa > 传感器量程 100 kPa 的盲区是否降阈值（建议 90）。

## 附录：泵参数溯源（2026-09-22，用户质询触发）

| 常数 | 当前值 | 来源 | 到货后动作 |
|---|---|---|---|
| PUMP_P_MIN_KPA | -58.0 | **370 Mini Vacuum Pump 规格书**（DFRobot FIT0801 ≥-58kPa，`literature/370-pump-FIT0801-spec.md`） | calibrate_pump.py 实测复核 |
| PUMP_P_MAX_KPA | 61.0 | FlowIO Small 实测死点（Shtarbanov thesis Table 2；370 正压规格书无单值 60-100 型号相关） | **必须实测**（calibrate_pump.py） |
| PUMP_C | 9e-8 | 按 FlowIO 实测充压曲线拟合（大容积执行器时标） | **必须实测**（小容积升压率比对） |

时间尺度诚实说明：370 空载流量 2.2L/min ≈ 0.037L/s，直驱 7mL 汇流管理论充压远快于孪生当前时标——孪生时标锚定 FlowIO 文档级充气曲线（秒级，真实执行器容积下成立）。对 TinyML 无影响：泄漏检测标签窗口在**密封态**（泵停），与泵时标无关（宪法第 13 条）。到货三实验协议见 calibrate_pump.py 头注释。

## 物理 v2.1：多节点端口模型（2026-09-22，用户 bug 报告触发）

**触发**：用户实测发现 G 闭环后汇流管缓降而"端口1压力"纹丝不动。

**根因**：物理层只有汇流管单一气压节点；"端口压力"是 GUI 前端变量（阀开拷贝、阀关冻结），无仿真状态。更深层：端口泄漏被无条件作用于汇流管节点——物理上阀关后端口侧泄漏对汇流管传感器不可见，v3 ML 训练数据因此含物理上不成立的签名。

**v2.1 模型**：
1. 每端口独立节点 `s_port_p[5]`：关阀瞬间快照汇流管压力，此后独立演化（自身密封微漏 1%/s + 端口泄漏孔口流）；开阀时与汇流管同节点
2. 开阀混合的端口初压用端口节点真值（原假设大气压）；关阀快照 `s_prev_ports` 检测
3. 端口泄漏（idx 0-4）移至端口侧：阀开对汇流管可见、阀关不可见（`ports_p` 可见）
4. 基线微漏条件修正：泵侧密封即适用（含 H 诊断保压的端口全通态），不再要求端口全关
5. 新增 CLI `H <ports>`（pn_hold_open）：泵侧密封+端口保持通 = 泄漏诊断的标准工况

**导出**：`pn_twin_port_pressure(idx)` → `/api/state.ports_p` → GUI 端口卡片（前端冻结 hack 删除）。

**ML v5 连锁修正**：工况改 H 语义；发现并修复采样率声明错误（每 tick 一点 = 20Hz，原标 50Hz 致斜率虚高 2.5 倍）；标签改物理可观测 Δ 分级（宪法第 12 条）；类平衡采样。终值：acc 95.73%、normal R 98.6%、major R 95.3%（零漏报为 normal）、18KB。

## 传感器模型对照 XGZP6897D-C 手册 V1.1（2026-09-23，用户指令触发）

**手册原件**：`literature/xgzp6897d-c-datasheet-v1.1.pdf`（16 页，CFSensor 官方）

### 驱动级修正（到货前必须改完，原实现三处错误到货必炸）

| 项 | 原实现（错） | 手册 | 修正 |
|---|---|---|---|
| I2C 地址 | 0x6D/0x5D | **固定 0x58**（-C 型选型码即地址，不可定制） | ✅ hal_esp32.c 已改；双传感器必须 TCA9548A |
| 读法 | 写 0x30←0x0A 启动→轮询→读 0x06 | **从 0x04 连读 5 字节**（ASIC 自动刷新，无启动命令） | ✅ 已改 |
| 换算 | K=2^24/span | **P[Pa]=补码和/2^21×(PMAX−PMIN)**（±100kPa 型 span=200000） | ✅ 已改（原差 8 倍） |

### 孪生传感器模型参数（手册锚点）

| 参数 | 手册值 | 孪生处理 |
|---|---|---|
| 量程饱和 | ±100 kPa（C100KPDPN 型） | ✅ 已建模（SENSOR_SPAN_KPA） |
| 精度 | ±2.5%FS（线性+重复+迟滞总量） | 文档化；系统性分量经上电零点自校准消除（装配指南 bring-up 步骤） |
| 零点漂移 | ±1%FS（回流后，±2kPa） | ML 域随机化按校准后残差 N(0,0.5) 建模 |
| 响应时间 | 2.5ms@OSR1024 | <50ms tick，忽略 ✅ |
| 上电启动 | 24ms | 忽略（<tick）✅ |
| 量化 | 24bit/2^21×200kPa ≈ 0.1Pa | 忽略 ✅ |

**ML 最终指标（手册随机化并入后）**：acc 94.5%（int8）/ normal R 99.4% / major R 96.2% / 18KB；种子固定（seed=42）消除训练方差（normal R 曾在 92.7↔99.9% 摆动）；不可测死区 Δ<0.25 kPa 归 normal。

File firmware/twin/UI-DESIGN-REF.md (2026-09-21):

# UI-DESIGN-REF — 界面设计参考（PneUI + FlowIO 官方 GUI 驱动）

> 状态：**待用户审查**。文献依据：PneUI（UIST'13）、FlowIO（CHI'21）——全文见 `../../literature/`
> 现行 gui.html 已具备：官方拓扑 SVG、全路径气流、端口卡片、Scheduler、三层测试（106 项）

## 1. PneUI 的可借鉴设计原则

| PneUI 原则 | 现状 | 改进建议（P2，审查后实施） |
|---|---|---|
| **压力→形变连续映射**（bending 随气压连续加深为 curling） | 气球仅有缩放 | 端口图形按压力连续演化：小→胀→颈缩三态连续插值；或提供"弯曲执行器"端口类型（弧线弯曲角随压力） |
| 形变方向由材料设计决定（各向异性） | 不适用 | 端口类型档案：气球/弯曲臂/波纹管——影响 SVG 图形与 Scheduler 语义（教学场景有用） |
| 交互词汇自明（stretch/bend/embrace/stroke/squeeze） | 充/保/释/抽 | 保持现行中文动词（已自明）；卡片可加执行器类型图标 |
| 亚秒级响应目标 | 200ms 轮询 ✓ | 已达标 |

## 2. FlowIO 官方 GUI 特性对照

| 官方特性 | 现状 | 建议 |
|---|---|---|
| Web GUI 免安装（Web Bluetooth） | 本地孪生 HTTP | P2：真机接入后评估 Web Serial/BLE 直连 |
| **配置自适应**（换泵配置 GUI 一键适配，Fig.6） | 固定 P0 单泵 | P1 双泵（串/并联）时：配置档案切换 → SVG 双泵/汇流拓扑与规格包线随之变化 |
| 动作按钮 + PWM 滑块 + 多口同时动作 | ✓ 均已具备 | — |
| 压力单位（psi/kPa） | 仅 kPa | 加单位切换（官方规格以 psi 标注，±psi↔kPa 一键） |
| 规格包线 −26~+30 psi | 无显示 | 曲线图叠加传感器量程(±100kPa)与泵包线着色带（安全视觉边界） |
| 分时单传感器（Sensors++ 为每口独立） | S0/S1 语义已注明 | P1：多传感器面板 |

## 3. 建议实施顺序（与 PHYSICS-SPEC v2 解耦，可并行）

1. 单位切换 psi/kPa（半小时级）
2. 曲线图包线着色带（传感器量程 + 泵包线）
3. 端口执行器类型档案 + 形变连续演化图形（PneUI 式）
4. P1 双泵配置自适应（等硬件）

以上均为 gui.html 单文件内改进，三层测试随改随跑（`bash run_tests.sh`）。

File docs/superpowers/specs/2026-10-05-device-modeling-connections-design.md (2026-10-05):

# Spec: 数字孪生器件精确建模与连接图谱（device-modeling v1）

> 日期: 2026-10-05 · worktree: device-modeling（自 main 89191ea）· 状态: **待用户审查**
> 来源: 用户查验——孪生 3D"结构与连接都有错误"：①阀端子（引线）未与驱动连接建模；
> ②泵吸/充口被错误建模在侧面（真值=**顶置双嘴 ⌀4.2 垂直于轴线**，ZR370-03PM 图纸+实物照）；
> ③电磁阀/气泵/XGZP/硅胶管/三通建模失真；④**两个分装式模块的功能、内外电气/机械接口、
> 模块间连接从未显式建模**。
> 用户指示: aminer/github MCP 检索算法与开源库 baseline → 基于 datasheet 准确建模 →
> 准确连接（电气+机械）→ 集成。基于已重构源码（flowio 包，可维护性好）。

## 0. 问题陈述（当前孪生的三类错误）

| # | 错误 | 根因 |
|---|---|---|
| E1 | 器件几何失真：泵吸/充口在侧面（真值=**顶置双嘴 ⌀4.2 垂直于轴线**）；阀缺引线端子（F0520D/B 实物=红黑引线+2P 白壳，规格书+实拍照） | 旧建模按"带嘴盒子"近似，未按 datasheet 图纸建接口面 |
| E2 | 连接缺失：阀引线→2P 插座（J10-J23）、气管拓扑（泵↔S/V、歧管↔阀嘴、测压支路）在 3D/数据中均无实体 | 连接关系（电气/机械/气动）从未建模为数据 |
| E3 | 模块接口未定义：主模块/泵模块各自功能、对内/对外电气与机械接口、模块间连接（2 管+1 电缆）无规约 | 分装式决策（1h）落地时只做了"几何壳"，未做"接口契约" |

**建模输入已完备**（零缺口）：五器件一手 datasheet（registry/audit 🅰 级）+ 实物照 +
官方 FlowIO 3mf/照片（参照）——见 `docs/component-registry.md` 六元组。

## 1. 设计总纲：器件=三接口面实体，连接=三类边图谱

**第一原则**：每个器件 = **三接口面**（气动/电气/机械）+ 参数化几何（datasheet 图纸直推）；
每条连接 = 图谱中一条**带类型的边**（两端点必须存在于器件接口面且口径/类型匹配）。
模块 = 器件+内部边的**组合**，其对外接口面是模块间边的端点。**接口先于几何，几何服务于接口。**

## 2. 器件模型库（Device Descriptor + 参数化构建器）

每个器件 descriptor 三接口面（新增 `pneumatic_devices.*.geom3d` 块，datasheet 图纸直推+出处注释）：
```json
"pneumatic_ports":     [{"name":"OUT","pos":[x,y,z],"dir":[0,0,1],"dia":4.2,"kind":"barb"}],
"electrical_terminals":[{"name":"MOTOR","kind":"wire_2p","pos":..,"connector":"JST-XH2P 白壳"}],
"mech_mounts":         [{"kind":"C-flange-tab","pos":..}, {"kind":"bracket_ring","id":23}]
```

### 2.1 构建器（flowio/twin/devices3d/，FreeCAD Part=OCCT 内嵌，**零新依赖**）
| builder | 几何（datasheet 真值） | 接口面 |
|---|---|---|
| valve_f0520d.py | C 架本体 20.5×15×13 + 顶翻边 0.7 + 侧嘴 ⌀3.0×3.5 | 2 引线（红/黑）→2P 白壳视觉件；翻边机械位 |
| valve_f0520b.py | 本体 20×15×13 + 端段=总长 28 + N1 顶嘴 ⌀4.6 | 安装孔 ⌀2.0×2（有孔变体）；2 引线 |
| pump_zr370.py | **立式校正**：泵头 ⌀24×27.3 竖直 + 电机 ⌀24×31（正负极标识）+ **顶置双嘴 ⌀4.2×7.5（充/吸，垂直于轴线）** | 硅胶支架环位 ×2（脚距 46）；电机端子 ×2 |
| sensor_xgzp.py | 本体 10.6×7×3.5 + 双倒钩 P1/P2 ⌀3.22×2.4（顶置，P1 高压/P2 大气）+ SOIC8 鸥翼脚 | 板载焊接（8 焊盘） |
| fittings.py | 硅胶管段（ID3/ID5，三点弯路径）+ Kamoer 直通/变径 + 三通 | 两端倒钩口 |
| harness.py | 电气线束：阀 2P 引线（~60mm 视觉桩）→ J 插座；泵电缆 J23→泵端子 | 插头/插座端点 |

baseline 依据（已检索）：build123d/CadQuery（OCCT 系）为参数化器件建模 OSS 标准——
FreeCAD 内嵌 OCCT 同核，`Part` 工作台即可表达（make_manifold/make_pump_module 已证模式），
**不引入新依赖**；未来需 STEP 互操作再评估 build123d。

### 2.2 XGZP6897D 特别核验（用户提供微差压版 datasheet）
双倒钩 **P1=高压端/P2=低压端**、引脚 2=Vdd/6=SDA/7=SCL/8=GND/1-3-4-5 N/C、
本体 10.80×7.00×3.50/总高 9.61、倒钩 ⌀3.22/2.20×2.40/孔 ⌀0.90、焊盘 2.54/排距 7.96/10.40×8.42、
量程档 XGZP6897D100KPDPN（-100~100kPa DPN，I2C 0x6D，±2%Span）——与在档一致 ✓，
建模按此图直推（倒钩位置/朝向入 descriptor）。

## 3. 连接图谱（connections.json——三类边，机器可校验）

```json
"pneumatic_edges":  [{"from":"P1.OUT","to":"Main.S_wall","tube":{"id":5.0,"od":7.0,"len_mm":60,"bend":2}}, ...],
"electrical_edges": [{"from":"J23.2","to":"P1.MOTOR+","kind":"cable_2p","len_mm":150}, ...],
"mechanical_edges": [{"from":"P1.body","to":"BRK.ring","kind":"silicone_clamp"}, ...]
```
校验器（测试守门）：①每边两端点存在于器件 descriptor 接口面；②口径匹配（嘴径≥管 ID）；
③六动作语义路通（充/吸/排/保/测在图上可达）；④悬空端点=FAIL。
产出即 webapp 渲染数据源（管路/线束 3D 化）+ BRINGUP 接管指南的机器真值。

## 4. 模块接口规约（Module Interface Spec——用户指正的核心，独立文档 docs/module-interface-spec.md）

### 4.1 主模块（功能：控制与分配）
| 面 | 对内 | 对外 |
|----|---|---|
| 气动 | 板/歧管/阀阵（内部免维护） | 8×通道口（→手套）、S 口+V 口（→泵模块）、F 口（→大气）、引压口（→XGZP） |
| 电气 | 板载（阀驱动/传感/主控） | USB-C 电源输入（对外）；**J23 泵电机插座→穿壁电缆（→泵模块）** |
| 机械 | 板铜柱/阀支架/歧管卡座 | S/V 壁面快插板、出线孔 |

### 4.2 泵模块（功能：气源）
| 面 | 对内 | 对外 |
|----|---|---|
| 气动 | 泵双嘴→面板快插 | **双管（充/吸）→主模块 S/V 口** |
| 电气 | 电缆→泵电机端子 | **2P 插头←主模块 J23 引出电缆** |
| 机械 | 硅胶支架×2+底座（自足式） | —（桌面放置，无壳间紧固） |

**模块间连接=3 条边**：气管（充）+气管（吸）+电机电缆（2P）。任何一边缺失=功能降级
（缺气管=无气源；缺电缆=泵不转）——模块接口规约使其成为**显式装配检查项**。

## 5. 集成（孪生渲染）
- scene-3d：devices3d 精确模型替换盒近似；connections.json 驱动管路/线束 3D 渲染
  （替代现 tubes.stl 单件）；连接图数据到 Web UI（点击器件→高亮其三类连接）；
- 双态/爆炸态：连接边随爆炸端点跟随（管/线拉伸可视——分装式的教学价值可视化）。

## 6. baseline 研究结论（已检索 + 计划深挖）
- **OSS CAD**：build123d/CadQuery（OCCT 系 Python 参数化建模，STEP/BREP）为标准——
  **FreeCAD 内嵌 OCCT 同核，零新依赖采纳其表达范式**（builder-pattern）；
- **学术**（aminer MCP 已恢复，2026-10-05 检索落地 → docs/research/device-modeling-baseline.md）：
  🎯 Ruzarovsky 2025《Behaviour-Based Digital Twin for Electro-Pneumatic Actuator》
  **已下载全文并精读**（literature/ruzarovsky2025-*.pdf/.txt，res.mdpi.com CDN 绕 Akamai）。
  精读增量结论（详见研究笔记"精读落地"节）：
  ① 三级保真度实证：**"模拟量但无物理"与离散级输出完全相同**——可信度分水岭只在
  气动动态级，支持"默认 L1+L3、气动动态整档 P2、不做半吊子模拟级"；
  ② 式(6) Qn=C·Ath·√Δp（等温标称流量）为 P2 阀/管路建模优先口径（对齐 datasheet 标定）；
  式(4) 腔压 ODE 移植时 Aẋ→dV/dt 腔壁变形项；
  ③ P2 验收集加 **rise-time 误差 + 跟踪误差** 两断言（对齐 BRINGUP 实测）；
  ④ latent phase（指令→压力/运动响应延迟）为独立观测量；⑤ 该文为刚性缸+PLC 域，
  器件级几何不迁移，软体连续体仍归 RA-L 2022 杆理论（次级）。
  另：混合物理+数据建模（Cell Rep. Phys. Sci. 2022）；电磁阀 RUL/状态监测簇
  （P2 医疗安全叙事学术支点）。
- **官方参照**：资源/官方参考/official-3mf（FlowIO 原版模块几何）+ 官方照片（管路走线/
  腕带形态）——集成目视的对照基准；
- **GitHub MCP**：未在当前工具环境；开源库检索已用 WebSearch 完成（结论同上），
  Phase R 可加深（KiCad 3D 库/XGZP 现货 STEP 查证）。

## 7. 验收标准
1. **几何断言**：每器件 port/terminal/mount 的位/向/径 vs datasheet 图纸（参数化断言，带出处）；
2. **连接完备性**：connections.json 每边两端点存在+口径匹配+六动作语义路通+悬空端点=0；
3. **模块接口**：module-interface-spec.md 三类边齐+装配检查项显式；
4. **渲染目视**：泵口朝上/阀引线在位/管路走线 vs 官方参考图+实物照比对通过；
5. **全家桶**：现有全测试保持绿（器件建模不破坏既有契约）。

## 8. 决策点（✅ 2026-10-05 已裁定：全按推荐 A/A/A/A）
- **D1 建模内核 = A**：FreeCAD Part（OCCT 内嵌零依赖）。裁定理由：build123d 与 FreeCAD
  同属 OCCT 内核，可建形状等价——差异只在 API 舒适度 vs 依赖包袱；工程样机阶段稳定优先、
  项目已有 make_manifold/make_pump_module 成熟写法；未来需 STEP 互操作再评估 B。
- **D2 线束渲染深度 = A**：引线桩+2P 壳视觉件（P1.2 深度）。裁定理由：A="诚实的不精确"
  （回答"接没接、接到哪"），B="昂贵的伪精确"（壳内真实布线依赖机械布局定型，P1.2 布局
  还在动，路径会反复作废）；精确线长属机械冻结后阶段。
- **D3 F0520A/C 常开型 = A**：家族留档不进 BOM。裁定理由：NC 架构断电=保压（省电，
  FlowIO 同款已验证）；常开排气阀=断电泄压（对病人更安全）但运行中需持续供电关断——
  医疗级"断电保证泄压"的行业标准答案是**机械式泄压阀**（非电控），留 P2 安全设计
  专门研究笔记，不在 P1.2 顺手带过。
- **D4 线缆/管路路径 = A**：关键弯折点折线。裁定理由：折线每段长度可核算=硅胶管下料
  长度直接喂采购；样条的"自然垂形"依赖重力/管夹数据（现在没有），画出来是伪精确；
  视觉美感属后期打磨。

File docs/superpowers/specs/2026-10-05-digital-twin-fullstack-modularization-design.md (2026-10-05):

# Spec: 数字孪生产品全流程 SOP 与代码模块化（v2——全栈覆盖 + OOD 设计）

> 日期: 2026-10-05 · worktree: modularization（自 main 90213e6）· 状态: **批准执行（v2.1 三决策全 B + 备份前置）**
> 用户裁定（2026-10-05）：**先备份已跑通版本** → D1=B（types.h 全文件生成替换）/ D2=B（webapp 组件化重写）/
> D3=B（一次性全量重构，不分期）。
> 备份落位：tag `v1.1-pre-modularization` + 分支 `archive/pre-modularization`（均锚 90213e6，
> 含生产在线版本与全套守门绿状态——回滚即 `git reset --hard v1.1-pre-modularization`）。
> 来源: 用户指正——"SOP 的 skill 和代码模块化应覆盖数字孪生**产品研发的全流程**，而不只是布线；
> 代码模块化的目的是提高可维护性，因此引入自顶向下、自底向上、高内聚、低耦合、
> 抽象、继承、封装、多态等技巧。"
> 取代: `2026-10-05-sop-modularization-design.md`（v1：期 B 仅硬件七层、OOD 停留口号——两处缺口如实承认）。

## 0. 现状诚实评估（v1 的两处缺口）

**产品五位一体**：硬件域（sch→pcb→fab）/ 结构域（case/manifold/pump/assembly）/
固件域（pn_core/pn_hal/driver）/ 孪生域（electrical_sim/board_model/sim_engine/twin_api）/
呈现域（webapp/site/部署）。

| 层面 | v1 现状 | 缺口 |
|---|---|---|
| SOP skill（期 A） | 八节框架名义全流程 | **深度严重不均**：硬件/结构域深（血泪密集），固件/孪生/呈现三域合计不足 10 行（各一行测试命令）；变更矩阵 9 行里 7 行硬件侧 |
| 代码模块化（期 B） | truth/gen/route/geom/flows/netlist/testkit 七层 | **全在硬件侧**——firmware/twin/webapp/site 零覆盖；"高内聚低耦合"无接口/层次/多态实质设计 |

## 1. 设计总纲（自顶向下 × 自底向上双向）

**自顶向下**：从产品愿景分解——数字孪生 = 物理实体（板/结构/气路）与其数字镜像
（参数/模型/仿真/渲染）**共享同一份真值**（devices.json 单源），各域是该真值在不同
介质的投影（铜箔/塑料/C 代码/JS/网页）。架构第一原则：**真值到介质的映射必须是
生成的，不是手抄的**（-58→-60 那次三处手抄事故的根治）。

**自底向上**：从现有资产抽象——P1.1 已绿的全套测试/守门是行为基线，重构=换骨架不换行为
（产物逐字节对拍法，T4/T5 验证过的范式）。

## 2. 目标包结构（全栈，渐进迁移禁 big-bang）

```
flowio/                          # 可安装包（pip -e），全产品共享内核
  core/                          # ★ 抽象层（仅接口与基础类型，零域知识）
    interfaces.py                  # IActuator/ISensor/BaseModel/ITubeNet(ABC)
    truth.py                       # TruthSource：devices.json 封装载载+校验(只读属性)
    errors.py                      # 域异常层次(TruthError/GeomError/RouteError...)
  truth/                         # 真值层：schema/两段解析/pneumatic 谓词(T1 断言迁入)
  hw/                            # 硬件域(自 v1 期B收敛)：sch_gen/pcb_gen/route/(stage1-6,dsn_io,auto6)/netlist/drill
  geom/                          # 结构域：case_geom/device_geom/fcl/manifold/pump_module
  flows/                         # 气路流：flows/hotspots(pneu_geom 并入)
  twin/                          # ★ 孪生域(OOD 重构核心，§3)
  fwgen/                         # ★ 固件域：codegen(params.h 片段/驱动骨架注释块)
  webgen/                        # ★ 呈现域：codegen(params.js)+webapp 组件契约
  testkit/                       # check()/runner/L1-L5+电气仿真分层入口/对拍器(字节级)
  cli.py                         # flowio truth|hw|geom|flows|twin|fwgen|webgen|test|rebuild|codegen <subcmd>
```

## 3. OOD 实质设计（v1 缺失的技巧，逐一落点）

### 3.1 抽象（Abstract）——`core/interfaces.py`
```python
class IActuator(ABC):
    @abstractmethod
    def current(self, state: str) -> float: ...        # state ∈ pull_in/hold/economy/off
    @abstractmethod
    def effective_v(self, duty: float) -> float: ...    # duty×rail
class ISensor(ABC):
    @abstractmethod
    def read(self) -> "Sample": ...                     # +protocol 对象注入(I2CProtocol)
class BaseModel(ABC):
    @abstractmethod
    def params(self) -> "TruthView": ...                # 参数单源视图
    @abstractmethod
    def step(self, dt: float, inputs: dict) -> dict: ...
    @abstractmethod
    def reset(self) -> None: ...
```

### 3.2 继承（Inheritance）——参数化子类
```
IActuator ─┬─ Valve ─┬─ ValveF0520D(10Ω/±45kPa)      # 差异只在 TruthView 参数
           │         └─ ValveF0520B(15Ω/-45kPa)
           └─ PumpZR370(load 0.5A/±120-60kPa)
BaseModel ─┬─ ElectricalModel(准静态母线解=electrical_sim 重构)
           ├─ ThermalModel(板级热一阶=board_model 热段拆出)
           └─ PneumaticModel(p 板模型=board_model 气路段拆出)
BoardModel = 组合根(has-a 三模型, façade 对外)          # 组合优于继承(三模型正交)
```

### 3.3 封装（Encapsulation）
- `TruthSource`：私有 `_load/_validate`，公共只读属性；直接摸 dict 的旧代码一律经视图；
- 各域生成器私有几何常量构建过程，公共只暴露 `generate(out)`+`verify()`。

### 3.4 多态（Polymorphism）——三处消灭 if-else 链
1. 场景仿真：`total = sum(a.current(s) for a in actuators)`——**新增执行器类型零改仿真器**
   （未来无刷泵/比例阀接入=新增子类+真值条目）；
2. 测试 runner：`for m in board.models: m.step(dt)`——模型增减不动 runner；
3. 守门：`for g in gates: g.check(ctx)`——L1-L5/check_route/check_fab/电气仿真统一门协议。

### 3.5 三语参数生成（单一真值的终极形态，v1 完全没有）
```
devices.json ──flowio codegen──┬─ pn_core/params_gen.h    # C：#define 生成片段(DO NOT EDIT 头)
                               ├─ webapp/js/params_gen.js # TS/ES module
                               └─ twin/_params_gen.py     # py(直接 import truth 可省)
```
CI 守门：重生成后 `git diff --exit-code`——**手编生成物立即红**（-58→-60 漏改事故的机器级根治）。
固件 types.h 现有手写常量逐个迁入生成片段（合并策略：生成文件被 types.h include）。

## 4. SOP skill v2（期 A 深化——全流程十二节）

| 节 | v1 状态 | v2 动作 |
|----|---|---|
| 0-1 愿景/真值链 | 真值链已有 | 增§0 产品五位一体与真值-介质映射图；真值链扩展固件/呈现（codegen 路径） |
| 2 变更矩阵 | 9 行(7 硬件) | **增 6 行**：固件常量改(走 codegen 勿手编)/孪生模型改(锚点钉值流程)/webapp 改(ES ./+47 测)/传感换型/执行器加型(IActuator 子类三步)/参数改(三语重生成+CI 门) |
| 3 五层测试 | 已全 | 增电气仿真层/守门统一门协议说明 |
| 4 环境铁律 | 16 条 | 保持，增 codegen 手编禁令 |
| 5 硬件流程 | 深 | 收敛为 hw+geom 两节（内容不减） |
| **6 固件开发流程** | 无 | **新**：driver-spec(唯一规格源)→组件实现→selftest→烧录；参数一律 params_gen.h |
| **7 孪生开发流程** | 一行 | **新**：BaseModel 子类开发模板(params/step/reset+锚点钉值测试)+场景矩阵扩展法 |
| **8 呈现域流程** | 无 | **新**：webapp 模块图/importmap/ES ./ 铁律/build_site/gh-pages/生产终验清单 |
| 9-12 评审/选型/部署/盲测 | 已有 | 保持 |
部署脚本 deploy_sop_skill.py 与 rebuild-matrix.json 随之扩（矩阵 +6 行、skill 十二节）。

## 5. 迁移分期（每期独立交付可中断，基线冻结+字节对拍）

| 期 | 内容 | 验收 |
|----|---|---|
| **M0 核心抽象** | core/(interfaces/truth/errors)+truth/ 迁入；electrical_sim 改经 TruthSource | L5/electrical_sim 全绿+行为锚点不变 |
| **M1 hw+geom+flows 挂载** | v1 期 B 七层收敛为子包；旧路径 shim | 全生成产物逐字节一致(uuid 归一化) |
| **M2 孪生域 OOD** | electrical_sim→ElectricalModel；board_model 拆 Thermal/Pneumatic；BoardModel 组合根 | 场景矩阵 12 数值逐一相等+run_tests 0 |
| **M3 三语 codegen** | fwgen/webgen；types.h/js 常量迁移；CI diff 门 | 手编实验翻红；三语常量三方对拍=devices.json |
| **M4 webapp 模块化** | js 七件按组件契约归位(importmap) | test_webapp 47/47+site 字节对拍 |
| **M5 cli+全回归+盲测** | flowio cli 全域；run_tests.sh 切 cli 双跑对拍后收；假想器件/模型全栈走通 | 盲测：新执行器类型三步接入零改仿真器 |
| **A2 SOP skill v2** | §4 十二节扩写+矩阵+6 行+重部署 | 与 M0 并行；盲测二轮 |

## 6. 不做的事（YAGNI）
- 不做微服务/进程隔离/插件市场——单包单进程够用；
- 不做 C 侧 OO（C 用 codegen+注释块，不硬上 C++）；
- webapp 不引入框架（原生 ES module+importmap 即可）；
- 不重写已绿的测试语义（只搬不改断言）。

## 7. 决策记录（2026-10-05 用户裁定：全 B）
- **D1=B 全文件替换**：`pn_core/types.h` 整体成为生成文件——`flowio fwgen` 产出
  （模板段：类型/枚举定义 + 参数段：devices.json 映射 #define），文件头 DO NOT EDIT；
  原手写常量的溯源注释逐条迁入生成器模板（事故出处不丢）。风险与对策：生成器自身
  bug 会波及类型定义 → M3 验收加"生成 types.h 与备份版 diff 逐行为等价语义（类型段
  字节一致+参数段仅值域受控变化）"对拍门。
- **D2=B 组件化重写**：webapp 以 Custom Elements + shadow DOM 重写（每面板一组件：
  DualPumpPWM/ChannelRow/FlowCanvas/TwinScene/TelemetryPanel…），importmap 管依赖；
  ES ./ 铁律保持。行为基线：test_webapp 47 条语义迁移（选择器适配组件 DOM），
  最终 47/47 等价覆盖+新增组件契约单测。
- **D3=B 一次性全量**：M0→M5 工程依赖顺序不变（抽象→挂载→孪生→codegen→web→cli），
  但**交付节奏合一**——一个 worktree 一次走完，末端一次双阶段评审+对拍+合并。
  内部检查点不省略：每步 commit+相关测试绿（守门是纪律不是阶段）；中断恢复靠
  worktree 内 commit 序列（铁律 16 范式）。
- **回滚线**：备份 tag/archive 如上；重构若最终验收不过且无法修复，主树 reset 备份即恢复生产。

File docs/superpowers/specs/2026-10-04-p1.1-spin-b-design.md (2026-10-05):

# Spec: FLOWIO-CN P1.1 平台化改版（分装式气动平台：主模块+泵模块 · 缺陷清零 + 阀/泵/传感国产化集成）

> 日期: 2026-10-04 · **v3.6 终版（2026-10-05 用户七项决策全部定案，§4）** · 分支: p1.1-spin-b · 状态: **待批准执行**（2026-10-05 校准：4.5V/3.7V 两档分工定案——P1.1=4.5V 参数有据；P2 电池泵模块=3.7V 直驱；详见 §2.1/§2.3）
> 决策变更（用户 2026-10-04 指示）：①板**未下单**，可改且必须改到零问题（逻辑+工艺）；
> ②电磁阀板载/压力传感器/外部供电并入**当前版本**一次做完；③**不使用电池/充电**（纯外供）；
> ④端子高度用 JLC 数据源终裁，不依赖到货量尺。⑤Tnkr 应用已卸载 ✓。
> 追加硬约束（2026-10-05）：⑥气动件**全国产 + 淘宝/1688 可购**（阀/泵/传感，追溯表
> `docs/component-registry.md`）。

## 1. 缺陷清零清单（P1 板 5 项 + v3 新增 1 项，全部在本版修复）

| # | 问题 | 根因 | 修复动作 |
|---|---|---|---|
| 1 | C9(1206) 压 J9 XH 壳体 | 布局时未查壳投影 | KiCad 移 C9 出壳体投影区，重布局部 |
| 2 | R3(100k) 藏 U1 WROOM 罩下 | 未遵守模块禁布 | 移出模块禁布区（WROOM 周边留 3mm） |
| 3 | J15/J16 压 M3 孔(68,65) | 孔位与端子排冲突 | HD 安装孔移位（候选 (72,65) 或端子排整体让位），case_geom.ST 同步 + 钻孔对拍自动验证 |
| 4 | 2 过孔擦铜柱接触环 | 布线余量不足 | 过孔各移 ≥0.5mm |
| 5 | 端子高度"两说" | KiCad 封装 3D 偏移噪声 | **终裁 14.0mm**：JLC 属性 14.07 + 型号尾缀 14-00A 双源一致；修正封装 offset(+3.5z)；壳链维持 26.07 |
| 6 | **J1 DC005(C431533) 额定仅 500mA** | v2 才引入大电流执行器轨，旧输入口未复核 | **换型**：C720575 DC-044A-A200（3A/30V，体高 7.2mm）或按 1d 仅 USB-C 用 C165948（5A/20V）——JLC 属性一手核实（literature/power-input-spec.md） |

## 2. 集成设计（当前阶段完成，非 P2）

### 2.1 电磁阀板载（v2 定案 0520D/F；v3.5 增补：实物形态/真尺寸/电流两说兜底）
- **8× 0520D 两通常闭端口阀 + 1× 0520F 两位三通排气总阀**（用户供 datasheet，
  固件/孪生同源既定选型）：通电=充气（外部气源经进气口）、断电=**保压**、
  F 通电=全阵列**统一排气**——充/保/排 三态复刻；
- **3.7V 变体评估（2026-10-05 两轮修正终版·用户查证纠正）**：用户查证 listing SKU 确有
  3.7V 型号（阀/泵均有）——推翻"目录最低 4.5V"的旧论断；同时修正物理论证：共轨 PWM 下
  **轨道电流由功率决定**（2W→400mA@5V），与线圈电压档无关（"+22% 电流"仅对直驱成立）。
  两档 5V 轨真实差异=占空比深度（4.5V→80% / 3.7V→54%）与参数文档化（4.5V 列在规格表、
  3.7V 列缺失无据）。**裁定：P1.1 主 BOM 维持 4.5V**（参数有据+占空比浅+与 5V 轨匹配）；
  **致荣采购单加 3.7V 样品**（F0520D-3.7V×1 + ZR370-03PM-3.7V×1 ≈¥11）——30V/10A 电源
  设 3.7V 实测线圈电阻/吸合/压比，参数补齐后 P2 电池泵模块（1S 锂电直驱免升压）按 3.7V
  选型；若用户改判"电池原生优先"，全 BOM 切 3.7V 以商家补充参数表为前置。
- **✅ 两档分工定案（用户认可）**：**P1.1 全系 4.5V**（参数有据+占空比浅+轨匹配）；
  **P2 电池泵模块主选=4.5V+升压**（一颗 IC，参数有据确定性优先）——同型号同 2P 接口，
  切换零成本、随时可逆（分装式红利）；3.7V **降为条件路线**：参数表暂不可得（2026-10-05），
  样品×3 实测自采数据（30V/10A 电源）或商家补表后再评。
- **实物形态（v3.5 图纸+实物照精读修正，literature/valve-0520df-spec.md §4）**：
  C 形架+红黑引线+2P 白壳连接器（**非 THT 直插**）→ PCB 挂 **11× 2P 卧贴插座**，
  阀体固定印刷支架/歧管（D 用 0.7 翻边、F 选有孔变体 ⌀2.0 孔×2）；
  真尺寸 D≈20×13×13 / F≈15.2×13×17.5（嘴 ⌀3.0~3.5→3mm 管，原 61/68mm 档作废）；
- **电流两说（设计已兜底）**：datasheet 文本 240mA/1.6W（内部不自洽+范文错漏）vs
  档案 D 85mA/F 320mA（商家确认）+ 渠道行业带 18~30Ω（150~250mA，240mA 概率大）
  → **预算按最坏 240mA/只**：β 最坏并发 10 阀=2.4A+泵 0.5A=2.9A<3A ✓；
  关闭：BRINGUP 测线圈电阻（≈19/50/14Ω 三档判据）+ 商家问询单
  （literature/valve-vendor-questionnaire.md，用户转发）；若定案 240mA →
  适配器升 5V/4A 或固件泵软启动互锁（峰值 3.4A 瞬态）+ T6 壳体通风；
- ⚠ **v3.2 发现架构缺口**：此拓扑**做不了每通道真空**（通道口只连充气歧管，无到泵
  吸气口路径），而 Vacuum 是 FlowIO 六动作之一（parity 已承诺）→ 新决策点 **1f**；
- **DFR0866 替代评估=否决**（6V 欠压 70% 功率吸合风险 + 40kPa 压比 < 泵真空 -58kPa +
  3-way 单阀做不全六动作；详见 literature/dfrobot-fit0801-dfr0866-eval.md——
  4.5V 直挂 5V 轨才是零变换复杂度，"电压高=体积大"不成立，压比才是体积主因）；
- 驱动：现有 8 路 AO3400+SS14 复用 + 新增路数随 1f 裁定（α=+1 路，β=+4 路）；
- 5V 阀轨直供（4.5V 额定，5V 下电流 +11% 在规格内）。
- 歧管：3D 打印（1 进 + 8 出 + 1 测量位 + 排气汇集至 F）；
- 气嘴 Φ3.2：3mm 管过盈直插或 JT-709 变径到 4mm（装配指南已有预案）。

### 2.2 压力传感（v3.5 主选切换：XGZP6897D 非-C——淘宝闽芯店在售 SKU，追溯链最短）
- **BOM=XGZP6897D 100KPDPN（非-C）**：I2C **0x6D**、**±2%Span**（略优于 -C 的 ±2.5%FS）、
  24bit、2.5~5.5V、ESD 4kV、过载 2×、待机 100nA；**寄存器手册全收**
  （0x30 CMD 0x0A 组合采集→Sco 轮询→0x06-08 24bit 数据，`P=ADC/k` k 表按 Span 查：
  Span200→k=32；温度/256——`component-registry.md` §3 即驱动规格，T7 直落地）；
- 引脚与 -C 兼容（2=Vdd/6=SDA/7=SCL/8=GND/1-3-4-5 禁连；上拉 4.7k；VDD-GND 0.1µF）；
  几何同族：本体 10.6×7×3.5（总高 9.5 含倒钩）、倒钩 ⌀3.22/孔 ⌀0.9→**3mm 管（阀侧统一）**、
  **P1=高压端接管/P2=低压端大气开放（表压读法）**、焊盘 2.54 节距；
- -C 变体（0x58，`xgzp6897d-c-spec.md` 全档）降为备选；
- TOY0058/BMP180 否决维持（绝对压/无气口/模块形态，`sensor-pressure-eval.md`；
  BMP390 环境基准留 P2）；数量：决策 3（1× 分时推荐）。
- **TOY0058/BMP180 评估=否决（2026-10-05 用户推荐后复核）**：绝对压量程 300~1100hPa
  （+50kPa 表压=1513hPa 超上限 37%）、**无气口**（裸片小孔测环境大气，不能接管）、
  评估模块形态不可入整机——三类硬伤，见 literature/sensor-pressure-eval.md；
  BMP390 裸片环境基准留作 P2 可选项。

### 2.3 供电（v3 大简化：单一 5V，纯外部，无电池）
- **全部执行器同为 5V 系**（阀 4.5V 额定 5V 直供合法 + 泵 370 族 1.5~6V）→
  **删除 12V 支路与新增 buck**：单一 5V/3A 外部适配器 → 5V 执行器母线
  （8D 0.75A + F 0.36A + 泵启动 ~1A，峰值 ≈2.1A）→ 现有 TPS54331 → 3.3V。
- 输入形式（决策点 1d）：DC005 换 5V/3A 型 + USB-C 并存（或门）vs **仅 USB-C PD
  5V/3A 单口**（省一个插座，手机充电头即用——推荐评估）。

### 2.4 微型泵（v3.5 定案：ZR370-03PM，替代 FIT0801——国产淘宝链+充气压一手标注）
- 1× **ZR370-03PM**（致荣华冠，用户供全档）：有刷隔膜 **⌀24 泵头×58.1 总长**、
  **双顶嘴 ⌀4.2×2（充/吸口固定，反接不换向）**；4.5V 负载 **<500mA**（<2W，
  电压范围 4.05~4.95V→固件 PWM 上限 ~95%）；**充 +120kPa / 吸 -60kPa**、≥2.8LPM、
  <60dB（垫海绵）、60g、寿命 3 万次循环（10s/5s 间歇=duty 模型同源）；
- 安装：**致荣硅胶支架**（环 ID23 配 ⌀24 头，脚距 46mm M3）×2 前后夹持——
  免自研软垫座，减振+固定一体（literature/硅胶支架.pdf）；
- 驱动：+1 路 Q14 AO3400+SS14，PWM 调速；**过压防护见 §2.6（泵死头 120kPa>>阀额定）**；
- 档案：`ZR370-03PM.pdf`；FIT0801/ZR370-02PM 降为参考（`component-registry.md` §2）。

### 2.5 原版官方图解对照（2026-10-05 用户供图精读，详见 docs/flowio-parity-gap.md §1b）
- **爆炸图=两套装配栈**：泵模块独立（壳+驱动板+微泵+电池+底座）；主模块=顶壳(5 气口)
  → MCU 独立小板 → 主驱动板（**阀排+硅管+压力传感板载**）→ LiPo 薄层 → 底座；
- **本 spec 三大方向获原版铁证**：①阀装板上+管路可视+顶部气口阵列（=1a 竖装同源）；
  ②泵自成一体的"源"单元（我们等价集成=泵舱+Q14 驱动，且单泵充吸两用覆盖 S/M 分档语义）；
  ③六动作语义（充/吸/泄/保/测/变速）10 通道全覆盖；
- **显式取舍**：原版模块化（泵分体、MCU 小板、电池层）→ 我们一体化单板单盒
  （B2B 开箱即用；ESP32-S3 单板省一层；无电池=用户明确要求）——模块化留 P2 生态位。

### 2.6 过压防护（v3.5 新增硬约束——ZR370 死头能力 vs 阀额定）
- 量化：ZR370-03PM 死头 **+120kPa/-60kPa** >> F0520 阀额定 **±45kPa**（350mmHg）
  → 气路任一密闭段（泵开+通道全关）即超阀额定；
- **闭环调压强制（非可选）**：XGZP 实时监测歧管 M + 泵 PWM 调速，工作带 **≤+35kPa / ≥-35kPa**
  （康复工作点 20~30kPa 落在阀额定内）；固件互锁：泵运转必须 ≥1 通道阀开启；
  真空钳位由 -50 收紧至 **-40kPa**；XGZP 过压即停泵+告警；
- P2 可选：50kPa 机械泄压阀（硬件保险冗余，B2B 认证叙事加分）。

**国产化追溯（用户 2026-10-05 硬约束）**：阀/泵/传感全部国产+淘宝可购——
致荣华冠（阀/泵/支架/管）、CFSensor 闽芯店（传感）、Kamoer（转接）、JLC（电子料）；
全器件"型号↔店铺↔一手档↔参数↔状态"闭环见 **`docs/component-registry.md`**（单一追溯源）。

### 2.7 数字孪生阶段强制要求（2026-10-05 用户两条提示 → 验收门槛）
> 背景：P1 两次失败模式——①驱动电压/电流参数反复出错（85/240/450mA 三说、5V 直驱超功率、
> 最坏 4.55A>3A 口）；②布局/布线/建模/装配缺算法守门导致装配错误返工。本版数字孪生（T6/T7）
> 必须把两者固化为**可执行断言**，不允许"到实物才发现"。

**2.7.1 电气驱动仿真层（提示①）**
- 模型：从 devices.json `pneumatic_devices` 读取线圈电流/电压窗/PWM 策略/泵负载——参数单源，
  改库即改仿真（禁双份手抄）；
- 孪生输出：每个气动动作仿真的**母线电流轨迹、各阀有效电压/占空比、瞬时与稳态功率**；
- 场景矩阵（至少）：单通道充/吸/排/保、典型 1-3 通道充气、最坏 9 阀全开保持+泵、
  搬气（S+V+D）、过压工况（M>35kPa 停泵路径）；
- **验收断言（T7 红/绿）**：①任意场景稳态母线电流 ≤ 适配器档（初值 3A，BRINGUP 后可调）；
  ②任意稳态执行器有效电压 ∈ [4.05, 4.95]V；③泵占空比 ≤95% 且软启动互锁触发正确；
  ④过压停泵+告警路径仿真通过；⑤场景矩阵全跑无异常。

**2.7.2 布局/布线/建模/装配算法守门清单（提示②）**
| 关卡 | 算法/工具 | 通过判据 |
|---|---|---|
| 布局 | placement_advice（网表电气边+域亲和+EDGE_OUT 约束）出候选 | L5 断言全绿（朝向/贴边/槽匹配/钻孔避让/refs 匹配） |
| 布线 | freerouting（调参记录在案） | 0 未连 + DRC 0 错 + KRT 连通性复核 |
| 建模 | FreeCAD 参数化壳 + parse_stl 纯 python 断言 | Matrix 列向量铁律；分项 bbox 断言（禁总盒宽松断言） |
| 装配 | make_assembly 装配契约 + 爆炸态两两分离 | L3 场景 bbox 同源 + 爆炸分离断言 |
| 干涉 | python-FCL 布尔（主壳/歧管/泵模块壳各自+合体） | 全部 0.000mm³ |
| 参数单源 | devices.json（devices + pneumatic_devices 两段） | 改一处全链重生成 |

## 3. 板面与结构影响（决策 2 已定：倾向微扩 ~100×80，T3 试摆终定）
11× 2P 插座 + 竖装阀阵 76×38mm + 12 路驱动 + 传感 + USB-C 在 90×75 上略挤：
- **定案方向**：微扩至 ~100×80，最终由 T3 placement_advice 试摆定（±5mm 内）；
- 1h 分装式：泵不在主壳/板上——主壳内仅 板+阀阵+歧管+传感，泵独立模块壳
  （ZR370-03PM + 硅胶支架×2 + 2P 航空插/JST + 双快插气口面板）；
- L1-L5 断言集不变（阀=EDGE_OUT+pneumatic+与驱动同域；新增泵模块壳独立断言）。
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

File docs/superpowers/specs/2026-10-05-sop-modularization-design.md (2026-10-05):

# Spec: FLOWIO-CN SOP 沉淀（工具链模块化 + 流程 Skill 化 + 布线算法决策）

> 日期: 2026-10-05 · 分支: p1.1-spin-b · 状态: **批准执行**（S1/S2/S3 全部落定 2026-10-05）
> 来源: 用户指示——"逐渐形成了一套 SOP，程序层面应形成可复用的低耦合高内聚模块，
> 流程层面形成 SOP 的 skill，以便未来不同环节调整后的重新走流程"+"算法条件松弛、
> 升级可微分？思考清楚优化目标与约束"。
> 时序约束: **期 A（纯文档）立即可做；期 B（代码重构）排在 P1.1 T8 之后**——
> 与正在执行的 T4/T5 撞文件（route_pcb/gen_pcb 等），big-bang 重构会毁掉收敛中的布线。

## 1. 布线算法决策记录（回应"可微分化"）
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

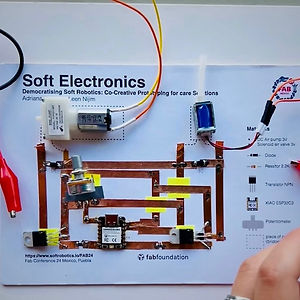
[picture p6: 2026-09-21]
flowio-softrobotics-docs/images/fab24_8_4__20PaperElectronics.jpeg

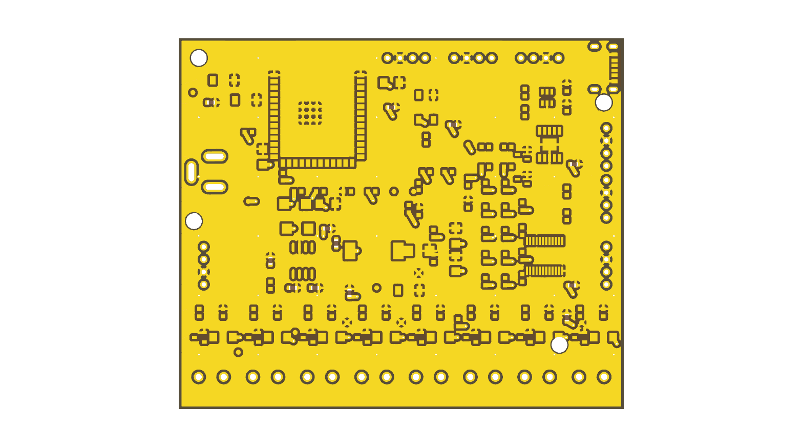
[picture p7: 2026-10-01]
hardware/flowio-p1/render_top.png

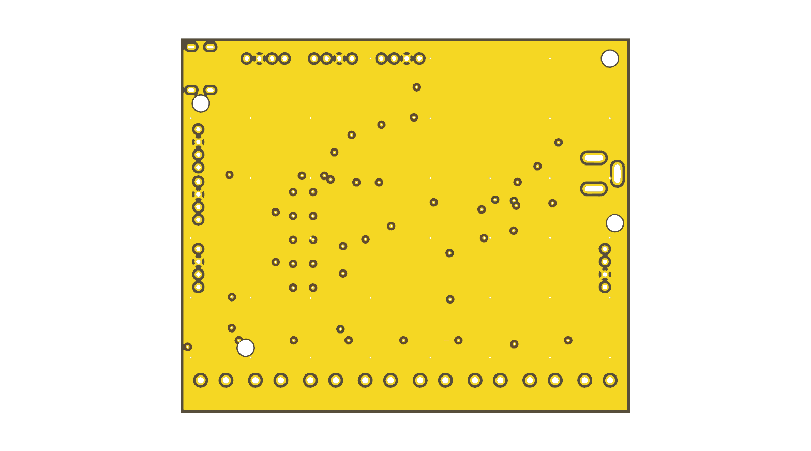
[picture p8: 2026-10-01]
hardware/flowio-p1/render_bottom.png

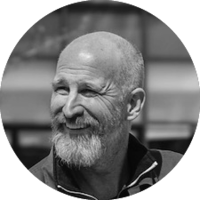
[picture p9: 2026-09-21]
flowio-softrobotics-docs/images/fab24_15_graphics-ezgif_com-instagif.png

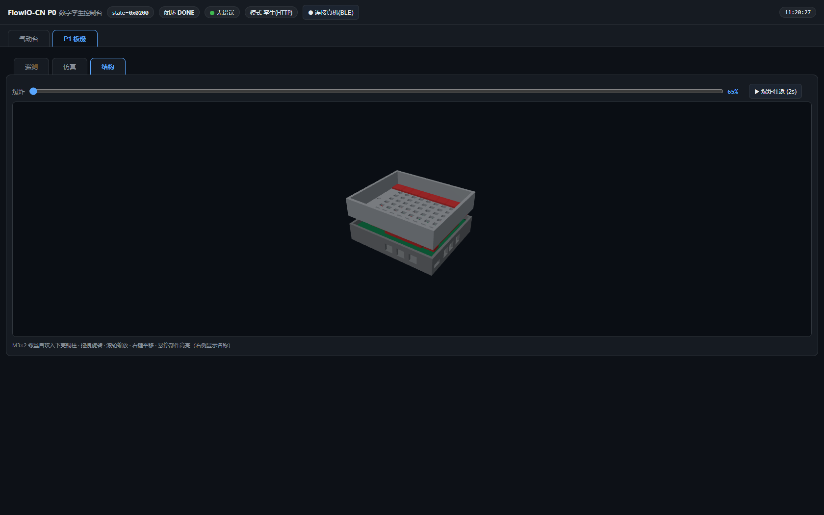
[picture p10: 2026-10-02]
book/figures/p1_structure.png

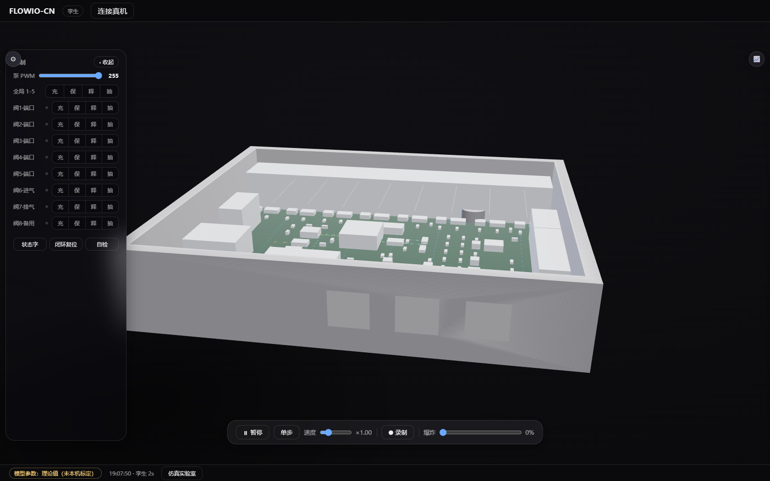
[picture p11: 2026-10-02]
book/figures/v2_10_recovered.png

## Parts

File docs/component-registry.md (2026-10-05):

# FLOWIO-CN 器件追溯注册表（Component Registry）

> **目的**：全器件"型号↔厂商/店铺↔一手资料↔关键参数↔选型状态↔关联决策"闭环，满足完全可追溯。
> **硬约束（用户 2026-10-05）**：气动三件（阀/泵/传感）必须**国产 + 淘宝/1688 可购**。
> **数据等级**：🅰官方/卖家 datasheet 一手 🅱店铺 listing 页 🅲推定待实测。
> **配套**：几何/电气入 CAD 链的真值另见 `hardware/flowio-p1/enclosure/devices.json`（T1 同步）；
> 本表是采购与档案面。更新规则：任何参数变化先改本表再改 devices.json，commit 关联。

## 0. 供应商总览（全部国产）

| 店铺/厂商 | 资质 | 供货 | 本地证据 |
|---|---|---|---|
| **东莞市政荣真空设备有限公司**（淘宝企业店"致荣华冠"） | 企业店，出厂前检测，7 天无理由 | 阀 F0520 族、泵 ZR370 族、硅胶支架、硅胶管、转接 | 本节各 PDF（listing+规格书合订） |
| **CFSensor（信泰/闽芯系）**（深圳闽芯半导体淘宝店） | 厂商系店铺 | XGZP6897D 系压力传感 | `XGZP6897D微差压传感器.pdf` |
| **Kamoer 卡默尔**（上海，流体品牌） | 品牌方 | 倒钩直通/变径转接头 | `透明转接头.pdf` |
| 惠州市百乘电子（淘宝） | 厂商规格书 | 0520D/F 阀（备选源，问询中） | `资源/器件规格书/电磁阀0520D/F*.pdf` |
| JLC/立创商城 | 平台 | 全部 SMT 电子料（AO3400/SS14/TCA9548A/USB-C/DC-044 等） | `literature/C*.pdf` + JLC 属性 |
| 乐鑫/武汉芯（沁恒）等 | 原厂 | ESP32-S3-WROOM-1 / CH340N / TPS54331 | `资源/器件规格书/数据手册/` |

## 1. 气动阀（11× 2/2 常闭 + 1× 负压专用，1f-β 架构）

| 位号 | 型号 | 关键参数 | 数量 | 档案 | 状态 |
|---|---|---|---|---|---|
| V1-V8 通道阀 / S 充气主阀 / F 排气主阀 | **F0520D**（致荣） | NC 2/2；4.5V **450±15mA**（<2W）；0~+350mmHg(≈+45kPa)；20.5×15×13；嘴 ⌀3.1/⌀3.2→3mm 管；绝缘 B；引线+2P 白壳 | 10 | `F0520D.pdf` 🅰 | **✅ 定案**（1i，2026-10-05 用户裁定；PWM 保持降流） |
| V 真空主阀 | **F0520B**（致荣） | NC 2/2 **负压专用** 0~-350mmHg(≈-45kPa)；4.5V 300±15mA；28×15×13；嘴 ⌀4.6 | 1 | `F0520B.pdf` 🅰 | **✅ 定案**（1i） |
| （备选源）同位号 | 惠州百乘 0520D/0520F | NC；240mA/320mA（datasheet 文本，行业带 18-30Ω 交叉吻合）；问询中 | 备 | `电磁阀0520D/F*.pdf`+`valve-0520df-spec.md` 🅰 | **⛔ 否决留档**（1i，用户裁定"坚决放弃"：参数表自相矛盾不可校正；问询单作废） |
| （否决留档） | F0520A/C（常开 NO） | 与 NC 架构不符 | 0 | `F0520A/C.pdf` | 不用（可追溯：NO 阀断电导通，破坏保压） |
| （否决留档） | DFR0866 | 6V 欠压/40kPa/三通单阀做不全六动作 | 0 | `dfrobot-fit0801-dfr0866-eval.md` | 否决 |

**驱动电压型号与功率预算（2026-10-05b 定案入 devices.json `pneumatic_devices` 段）**：
- **全系选 DC4.5V 变体**（F0520D-4.5V：450±15mA/4.05~4.95V/<2W；F0520B-4.5V：300±15mA；
  ZR370-03PM-4.5V：负载<500mA）——**维持 4.5V 档**
  （3.7V SKU 存在但规格表无参数列；采购单加 3.7V 样品×2 供 P2 电池模块预研实测）——6V 变体在 5V 轨=83% 欠压（吸合风险，DFR0866 同款否决逻辑），
  12/24V 变体更不可用；
- **驱动策略（PWM 调制，写入固件规格）**：阀=吸入 100%（≤100ms）→ 全开保持 90%（等效 4.5V=额定，
  规避 5V 直驱 2.5W>2W 超功率）→ 节能保持 55%（2.75V）；泵=上限 95% + 软启动互锁；
- **功率预算（诚实版）**：最坏 9 阀全开保持(90%)+泵 = **4.55A > 3A 口** → 全通道同时充气保持
  列为受限模式（错峰/并发上限），典型充气 1-3 通道=1.85A ✓；节能保持 9 阀+泵 = 2.75A ✓；
  **BRINGUP 实测 35kPa 背压下最小可靠保持占空比**后再定适配器档（3A/4A/5A）；
- **✅ 两档分工定案（用户认可）**：P1.1 全系 4.5V；P2 电池泵模块**主选=4.5V+升压**（3.7V 参数表暂不可得→条件路线：样品实测自采数据后重评）；同型号同接口切换零成本；
- **已入库**：`hardware/flowio-p1/enclosure/devices.json` 新增 `pneumatic_devices` 段
  （valves/valve_vacuum_master/pump/sensor 四组，含变体/电气/压力/dims/端口/安装/驱动策略/
  功率预算），回归 L1-L3 29/0 + L5 6/0 零破坏；T6 结构算法与 T7 固件从该段消费。

**阀域红线**：F0520 系额定 ±45kPa 级——见 §5 过压防护（泵死头 120kPa >> 阀额定，闭环强制）。
**待问商家**：D 通负压 -40kPa 可否（通道阀吸模式会受负压）？有孔变体孔位？2P 连接器型号？

## 2. 微型泵（气源，充吸双口）

| 项 | **ZR370-03PM**（致荣）★✅ 定案（1h 分装式泵模块） | ZR370-02PM（同店） | FIT0801（DFRobot，让位） |
|----|---|---|---|
| 几何 | **⌀24 泵头 ×58.1 总长**，双顶嘴 ⌀4.2×2 | ⌀27 头×58.2，顶+侧嘴 | ⌀27×58，双嘴 ⌀4.3 |
| 性能 | **充 +120kPa / 吸 -60kPa**、≥2.8LPM、<60dB(垫5cm海绵) | 同电气（正负压同表） | 吸 -58kPa/2.2LPM，正压未标 |
| 电气 | 4.5V 负载 **<500mA**（<2W），电压范围 4.05~4.95V | 同 | 1.5~5V/空载≤500mA |
| 机械 | 60g；有刷；充/吸口固定（反接不换向）；马达端 380°C≤2s 焊 | 同 | — |
| 配套 | **硅胶支架**（环 ID23 配 ⌀24 头，脚距 46mm）✓ | 需另配 | — |
| 档案 | `ZR370-03PM.pdf` 🅰 | `ZR370-02PM.pdf` 🅰 | `370-pump-FIT0801-spec.md` |
| **P2 变体（泵模块分档）** | **ZR370-01PM**（致荣）：**充气专用单口泵**——充 +120kPa、≥2.8LPM、<500mA@4.5V、⌀27×58.2、60g、**无负压能力** | `ZR370-01PM.pdf` 🅰 | 分装式即插即用（1h 红利）：不做主泵（会砍真空语义），定位"纯充气高压档"泵模块，对齐 FlowIO S/M/L 分档叙事 |

**✅ 定案（2026-10-05）**。定案理由：充气压力一手标注
**实验供电定案（2026-10-05）**：用户有 **30V/10A 直流稳压电源**——BRINGUP 参数测量用
5.0V/10A 模式（上限 10A >> 最坏 4.55A，无跌落干扰，保持占空比/启动电流/并发全开实测才准）；
CC 限流 3A 模式复现适配器跌落验证软件互锁；产品 BOM 不变（仍 USB-C）。

（120kPa，FIT0801 未标）+ 同店配套硅胶支架 +  listing/规格书齐全。
**注意**：5.0V 供电略超 4.95V 上限 1%→固件 PWM 上限 ~95% 占空比即可；寿命口径为 3 万次循环
（10s 开/5s 停）——间歇工况与孪生 duty 模型一致。

## 3. 压力传感（气路表压闭环）

| 项 | **XGZP6897D 100KPDPN**（非-C，闽芯店 ¥40.5）★✅ 定案 | XGZP6897D-**C**（备选） |
|----|---|---|
| 量程/类型 | -100~100kPa DPN 表压 | 同（C 后缀=I2C 0x58 变体） |
| 精度 | **±2%Span** | ±2.5%FS |
| 接口 | I2C **0x6D**、≤400kHz、24bit、上拉 4.7k | I2C 0x58 |
| 寄存器 | 0x01 PartID/0x02 Status/0x06-08 DATA/0x09-0A TEMP/0x30 CMD（0x0A 组合采集，Sco 轮询）；`P=ADC/k`（k 表：Span200→32）、温度 /256 | 0x04 连读 5B + 2^21 公式（`xgzp6897d-c-spec.md`） |
| 引脚 | 2=Vdd/6=SDA/7=SCL/8=GND/1-3-4-5 N/C（禁连） | 同 |
| 电源 | 2.5~5.5V（LDO 1.8/3.6 可选）、待机 100nA、ESD 4kV、过载 2× | 2.7~5.5V、ESD 2kV、过载 2.5× |
| 档案 | `XGZP6897D微差压传感器.pdf` 🅰 | `xgzp6897d-c-spec.md` + `-datasheet-v1.1.pdf` 🅰 |

**定案理由**：用户提供的淘宝在售 SKU+全文档（追溯链最短）；非-C 与 -C 引脚兼容，寄存器不同
→ **T7 固件按非-C 寄存器表实现**（本表 §3 即驱动规格）。否决留档：BMP180/TOY0058（绝对压/无气口）。

## 4. 电子料（JLC 贴片，国产供应链 ✓）

| 用途 | 型号/LCSC | 档案 | 状态 |
|---|---|---|---|
| 主控 | ESP32-S3-WROOM-1 | `数据手册/ESP32-S3-WROOM-1_EN.pdf` | ✅ 既有 |
| 5V→3.3V | TPS54331DR | `TPS54331DR_datasheet.pdf` | ✅ 既有 |
| 阀/泵低边驱动 | AO3400A ×12 | `AO3400A_datasheet.pdf` | ✅（泵启动/阀 450mA 均富余） |
| 续流二极管 | SS14（MDD C2480，基本库）×12 | `C2480_SS14_MDD.pdf` | ✅ |
| I2C 多路（仅 8× 传感方案） | TCA9548A | `tca9548a-datasheet-ti.pdf` | 备 |
| 电源输入口 | **C165948** TYPE-C-31-M-12（5A/20V）✅定案；DC-044 C720575 转备选留档 | `C165948_*.pdf`/`C720575_*.pdf` | **✅ 定案**（1d 仅 USB-C） |
| ⛔ 现口换型 | C431533 DC005 仅 500mA → 缺陷 #6 必换 | `power-input-spec.md` | 随 1d |
| 晶振/串口/座子 | ABLS 12MHz / CH340N / XH2.54-4PZZ / 电感 CDRH103RNP-6R8NC | `数据手册/` 各 PDF | ✅ 既有 |

## 5. 过压防护（新增硬约束——泵能力 vs 阀额定）

- 泵死头 **+120kPa / -60kPa** >> F0520 阀额定 **±45kPa** → 气路任一密闭段满压即超阀额定；
- **闭环调压强制**（非可选）：XGZP 实时监测歧管 M + 泵 PWM 调速，工作带目标 **≤+35kPa / ≥-35kPa**；
- 固件互锁：泵运转必须 ≥1 通道阀开启；真空钳位由 -50 收紧至 **-40kPa**；
- P2 可选：机械泄压阀 50kPa（保险冗余，B2B 认证叙事）；传 XGZP 过压即停泵告警。

## 6. 管路/结构件（致荣+Kamoer 配套）

| 项 | 规格 | 数量 | 档案 | 状态 |
|----|---|---|---|---|
| 硅胶管（阀/传感侧） | ID3×OD7 | 按米 | `硅胶管.pdf` 🅱 | 定案 |
| 硅胶管（泵侧） | ID5×OD7（配 ⌀4.2 嘴，到货试装 4/5 取一） | 按米 | 同上 | 定案 |
| 变径转接 | Kamoer 倒钩直通（3↔4.5mm 档；精确规格 T6 按嘴径实测定） | 数只 | `透明转接头.pdf` 🅰 | T6 定型 |
| 泵减振支架 | 致荣硅胶支架（环 ID23/OD26，脚距 46mm，M3 孔） | ×2 | `硅胶支架.pdf` 🅱 | **定案**（替代自研软垫座，T6 直接开孔固定） |
| 电源适配器 | 5V/3~4A USB-C PD（通用国产；致荣店适配器仅 24/12/6V 档不适用阀 4.5V，仅证渠道） | 1 | `电源适配器+电源线.pdf` 🅱 | 随 1d |

## 7. 决策与状态索引（联动 spec §4）

| 决策 | 内容 | 状态 |
|---|---|---|
| **1h** | 分装式 vs 一体化 | **阻塞点**，推荐分装 |
| 1a | 阀竖装 vs 横装 | **✅ 定案：竖装 2×4** |
| 1f | β 公共歧管 11 阀 vs α 维持 9 阀 | 推荐 β |
| **1i（新）** | 阀源：致荣 F0520D×10+B×1（文档全/同店生态，PWM 保持）vs 惠州 0520D（240mA 省电，问询中） | 推荐致荣（追溯链最短），惠州为备 |
| 1d | 输入口 | **✅ 定案：仅 USB-C（C165948）** |
| 3 | 传感 1× vs 8× | **✅ 定案：1× 分时** |
| 2 | 板面尺寸 | **✅ 定案：微扩 ~100×80，T3 试摆终定** |

**追溯更新记录**：2026-10-05 首版（泵 FIT0801→ZR370-03PM、传感主选转非-C、阀源双轨、过压防护入约束、支架/转接/硅胶管入 BOM）；
2026-10-05b **用户七项决策全部定案**（1h 分装/1i 致荣+弃惠州/1a 竖装/1f β/1d 仅 USB-C/3=1×/2 微扩 100×80），全表状态翻转。

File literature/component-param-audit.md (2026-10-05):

# 器件参数完备性审计（P1.1 · 2026-10-05，用户问"参数配置是否都准确"）

> 范围：0520D/F 阀、FIT0801 泵、XGZP6897D-C 传感。证据分级：🅰 官方/用户供 datasheet 一手
> 🅱 多源交叉归档 🅲 推定待实测。结论：**电气参数 100% 一手齐备；几何主体齐备、4 个小缺口
> 均有明确关闭路径（T3 建封装重读图纸 / T6 读图 / BRINGUP 实测），无一阻塞用户决策。**

## 1. 0520D×8 + 0520F×1 阀（🅰 用户供 datasheet 3页 + 供应商确认）

| 参数 | 0520D | 0520F | 状态 |
|---|---|---|---|
| 驱动 | 4.5V 额定/**5V 直供合法**（商家确认 +11%），85mA/0.38W | 320mA/1.44W，线圈 14.1Ω 三重自洽 | ✅ |
| 压力 | -53.3~+300kPa | ±100kPa | ✅ |
| 功能 | 2/2 常闭 | 3-way 断电 COM↔NC/通电 COM↔NO（NC 证据链） | ✅ |
| 外形 | 19×19×61mm | 21×33×68mm，**三口=底2+顶1** | ✅（总长档） |
| 气嘴 | Φ3.2 → 3mm 管 | 同 | ✅ |

**缺口①（T3）**：61/68 为含线总长——建 footprint 前从 datasheet 图纸剥离"本体/引脚(THT 焊盘
间距)/气嘴"三层真值。**缺口②（BRINGUP）**：重量未记录。朝向：port.dir_local 已建模，随 1a 定稿。

## 2. FIT0801 泵（🅰 官方 DFRobot PDF 一手）

- 电气：1.5~5V / 空载 ≤500mA / 2.5W / <60dB ✅；**启动电流 ~1A=🅲 同族归档推定，官方 PDF
  未标注 → BRINGUP 实测项**（3A 轨与 Q14 已按 1A 留裕量）；
- 几何：⌀27±0.3×58±0.5、泵头 27.3、电机 ⌀24.2、**双嘴 ⌀4.3±0.2（顶10/中7）** ✅；
- 端口语义：**侧口=吸气、中口=出气**（一手原文）✅；反接换向功能两口都接管路后用不到；
- 安装：图纸有孔距 10/槽 18.0/槽宽 2.0（🅱 分辨率有限）——已选**减振软垫座规避安装孔** ✅。

## 3. XGZP6897D-C 传感（🅰 V1.1 官方 PDF 文本层，2026-10-05 深挖 16 页）

- 电气：I2C 0x58、2.7~5.5V、休眠 <100nA ✅；
  **SOIC8 引脚定义已核：2=VDD / 6=SDA / 7=SCL / 8=GND / 1-3-4-5=N/C** ✅（T2 建符号直接用）；
- 量程：-100kPa…0~1kPa…200kPa 可定制、差压/表压型、**P2 低压端耐压 500kPa** ✅；
- 订货号结构已破解：`XGZP6897D-C - [D=I2C] - [C=0x58] - [量程000-999] - [KP=kPa] - [DPN=负压到正压]`
  → **✅ 缺口③已关闭（2026-10-05b 全版 datasheet 精读）**：**BOM=XGZP6897D-C100KPDPN**
  （-100~100kPa DPN，页 4 量程表标准档；C040KPDPN 因真空 -50 出程否决；
  高精度备选=定制 ±60kPa 档询厂）；
- 回流：峰值 200°C 上限（p8 曲线页，JLC 工艺兼容）✅；
- **✅ 缺口④已关闭（页 3 外形图直读）**：本体 10.6×7×3.5mm（总高 9.5 含倒钩）、
  倒钩 ⌀3.22/颈 ⌀2.2/高 2.4/内孔 ⌀0.9（3mm ID 管与阀侧统一，死端引压口）、
  P1=高压端/P2=低压端、焊盘 2.54 节距/排距 7.96（T3 封装直接用）、
  **N/C 脚 1-3-4-5 严禁连接**、精度 **±2.5%FS**（±100kPa 档≈±5kPa，康复控制可接受；
  回流零漂 ±1%FS→固件开机置零）、I2C 寄存器手册+换算公式全收（T7 固件输入）——
  详见 `xgzp6897d-c-spec.md`；

## 4. 决策点全景（2026-10-05 汇总，5 项待裁定）

| # | 决策 | 推荐 | 影响 |
|---|---|---|---|
| **1h** | **产品形态：分装式（跟原版 FlowIO：主模块+独立泵模块）vs 一体化（当前 spec）**——用户 2026-10-05b 提出，**当前唯一阻塞点** | **分装式**：本架构泵本就软管连接+独立减振，分装=把泵舱移出主壳成小盒（哑泵：电机 2 线回主板 Q14，气路 2 管 回 S/V 主阀外侧）——**PCB/固件零改动**；主壳显著缩小、有刷泵可换单、P2 泵模块分档不动主板、对齐"FlowIO 中国版"平台生态叙事 | T6 拆主壳+泵壳两件、BOM +~¥15（小壳/2 快接口/JST/软管）、孪生双体渲染 |
| 1a | 阀竖装 2×4（壳高~75）vs 横装（扁壳~35+复杂歧管） | 竖装 | T3/T6/devices.json 朝向 |
| 1f | β 公共歧管 11×0520D vs α 维持 8D+1F | β（六动作全通+单歧管+单泵搬气） | T2 通道数/T6/固件 |
| 1d | 仅 USB-C C165948 vs DC-044 C720575 vs 双口 | 仅 USB-C（5A/省插座/手机头即用） | T2/T3/J1 开槽 |
| 3 | 传感 1× 分时 vs 8× 并行 | 1×（P2 医疗安全版升 8×） | T2/T3/校准流程 |
| 2 | 板面尺寸 | 随 1a+1h 联动（竖装微扩；泵出壳后主壳 XY 可缩） | T3-T6 全链 |

已结案（无需再问）：阀型号 0520D/F、泵 FIT0801、传感型号 XGZP6897D-C、单 5V/3A 电源树、
端子高度 14.0、1g 阀轻量化（维持）、1e 泵细分（消解）、缺陷#6 DC005 换型（随 1d 落地）。

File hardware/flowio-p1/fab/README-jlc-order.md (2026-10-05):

# FLOWIO-P1.1 嘉立创全代工下单指南（PCBA 标准版 + 3D 打印代打）

> T5 重校 2026-10-05：板 100×80 布线终态 / BOM 39 行 146 件 / THT 仅 7 件（12× XH-2P 已改 SMD 卧贴）。

目标交付形态：**用户零手工焊**。JLC 完成 PCB 制造 + 139 件 SMT 贴焊 + 7 件 THT 代插代焊；
上下外壳 3D 代打。收货后只需拧 M3 螺丝装配 + 插线即用。

## 0. 上传文件清单

| 文件 | 用途 |
|---|---|
| `flowio-p1-jlc.zip` | PCB 制造 Gerber（**13 文件**：4 铜 + 双 Paste + 双 Silk + 双 Mask + Edge + gbrjob + drl；下单第一步上传） |
| `flowio-p1-bom-jlc.csv` | PCBA **BOM** 上传（39 行 / 146 件，全部带 LCSC 码） |
| `flowio-p1-pos-jlc.csv` | PCBA **CPL 坐标**上传（首 4 行 `#` 为说明注释；若上传器报表头错误，删掉 `#` 行再传） |
| `flowio-p1-pos.csv` | 原版无注释 CPL（备用，内容与上行完全一致） |
| `assembly-top.pdf` / `assembly-bottom.pdf` | 上贴位置人工核对图（Fab+CrtYd+Edge） |
| `../enclosure/case-top.stl` / `case-bottom.stl` | 3D 打印上传件 |

BOM/CPL 由 `tools/make_bom.py` 从 `tools/gen_sch.py` 的 PARTS 真值源生成，改料后重跑：
`cd hardware/flowio-p1/tools && python make_bom.py`（纯 stdlib，任意 python3 可跑）。

## 1. PCBA 下单步骤（jlc.com → PCB 制造 → 勾选"PCB 组装"）

1. **上传 Gerber** `flowio-p1-jlc.zip`，参数照 `README-fab.md`：
   4 层 / **100×80mm** / 板厚 1.6 / 最小线宽 0.2/0.2 / 过孔覆盖（阻焊塞孔）/ 白色丝印 /
   无需工艺边 / **表面处理选 ENIG**（XH 端子与塞孔可焊性）。
2. **组装类型选「标准版」**——硬约束，两个理由：
   - U1 `ESP32-S3-WROOM-1-N16R8`（C2913202）库属性为 **standard-only**，经济版无法上贴（已实测查询确认）；
   - J5-J9/J18/J19 共 **7 只 XH-4P 插件（THT）**需要标准版代插代焊——这是"零手工焊"的关键。
   （P1.1 起 J10-J17/J20-J23 共 **12 只 XH-2P 已是 SMD 卧贴**（C7429671），回流焊即可，不再计入 THT。）
3. 数量选 **5**（打样），上传 BOM `flowio-p1-bom-jlc.csv` 与 CPL `flowio-p1-pos-jlc.csv`。
4. **确认 BOM 解析**：39 行全部匹配出物料、无"无物料/缺码"行；所有上贴器件全部勾选
   （U6 XGZP6897D 为淘宝件 CFSensor，**不上贴自焊**；TP1-TP13 测试点与 HA-HD 安装孔为裸铜/板件孔不入 BOM，正常）。
5. **确认 CPL 解析**：位号共 **147 个、全部 top 面**。PosY 为负是 KiCad 向下 y 轴的导出方向，
   JLC 接受。核对法：任取 3 行对照 `assembly-top.pdf`——U1 应在板左上、J10-J17 应在板底边一排、
   J20-J23 应在板右边缘一列、J2 应在板右上角。
6. **下单留言栏抄录**（工艺备注，原文）：
   - 本板 13 处 via-in-pad（J20.1/J21.1/J22.1/J23.1/C2.1/U3.2/U5.2/U4.3/R4.1/LED1.1/R16.1/C9.1/R29.2），
     需 IPC-4761 Type VII（树脂塞孔+电镀封帽），否则焊膏流入孔桶造成虚焊；
   - 最小过孔孔距 0.274mm（壁距，≥ 贵司 0.2 限值；板内 DRC 已清零超距对）；
   - 表面处理 ENIG（XH 插件可焊性）。
7. 付款前看预览拼版图：顶面 139 SMT + 7 插件全部有位号标注，即正确。

## 2. 3D 打印下单（jlc.com → 3D 打印）

1. 分别上传 `hardware/flowio-p1/enclosure/case-top.stl` 与 `case-bottom.stl`。
2. 材料两档任选：
   - **PLA（默认推荐）**：结构强度够、最便宜；
   - **MJF 尼龙 PA12（若在列，进阶）**：强度/韧性/耐温最佳，适合长期按压的卡扣与螺柱，价高；
   - 树脂：表面细但脆，不建议用于承载外壳（仅外观件可用）。
3. 壁厚自检已过（≥1.2mm，水密网格已验证），无需再加厚。
4. **摆放方向**：上壳通风栅所在面**朝上平放**可减少支撑。JLC 默认可能自动转向——
   选"摆件需人工确认"，或下单备注"保持模型原始方向"；层高 0.1-0.2mm 均可。

## 3. 预期费用区间（按 5 片打样；估算仅供预算参考）

| 项 | 区间（元） |
|---|---|
| PCB（4 层 100×80 ×5，ENIG + 塞孔） | ~60-120 |
| 标准版贴装（工程费+钢网+上料+THT 代插×7） | ~300-600 |
| 5 套元器件物料（含 U1 ≈26 元） | ~150-300 |
| 3D 打印（两外壳） | ~50-150 |
| **合计** | **~560-1170**（不含运费） |

## 4. 不上贴 / 自购说明

- **JLC 不上贴：U6**（XGZP6897D 气压传感器，淘宝件无 LCSC 码）——到货后手工补焊
  （SO-8 手焊难度低，或与外壳装配同工序完成）；其余 145 件全部由 JLC 供料上贴/代插。
- 测试点 TP1-TP13 为裸铜焊盘、安装孔 HA-HD 为板件孔，均无实物器件、不入 BOM（正常）。
- 需自备的只是**使用耗材**：XH2.54-4P 对线、USB-C 数据线、12V DC 适配器、
  气路快插接头与气管、M3×6 螺丝×4（装壳）。

## 5. 收货验收清单

- [ ] 目检 U1 模块四侧焊脚、J5-J9/J18/J19 端子无歪斜/浮高，XH-2P 卧贴座无损脚
- [ ] 上电（12V 或 USB）：TP2 测 +5V、TP1 测 +3V3，LED2 (PWR) 亮
- [ ] 外壳试装：PCB 入下壳、四角 M3 孔对位（HA-HD），上壳按键对准 SW1/SW2/SW3
- [ ] 手工补焊 U6 后执行 BRINGUP 30 检查项（firmware/BRINGUP.md）

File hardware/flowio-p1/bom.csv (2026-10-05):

Refs | Value | Footprint | Qty | DNP
C1 | 10uF | JLC-MCP:C1206 | 1
C2 | 100nF | Capacitor_SMD:C_0603_1608Metric | 1
C3 | 2.2nF | Capacitor_SMD:C_0603_1608Metric | 1
C4 | 22pF | Capacitor_SMD:C_0603_1608Metric | 1
C5 | 100nF | Capacitor_SMD:C_0603_1608Metric | 1
C6 | 100nF | Capacitor_SMD:C_0603_1608Metric | 1
C7 | 100uF | JLC-MCP:C1206 | 1
C8 | 100uF | JLC-MCP:C1206 | 1
C9 | 10uF | JLC-MCP:C1206 | 1
C10 | 100nF | Capacitor_SMD:C_0603_1608Metric | 1
C11 | 100nF | Capacitor_SMD:C_0603_1608Metric | 1
C12 | 100nF | Capacitor_SMD:C_0603_1608Metric | 1
C13 | 100nF | Capacitor_SMD:C_0603_1608Metric | 1
C14 | 1uF | Capacitor_SMD:C_0603_1608Metric | 1
C15 | 100nF | Capacitor_SMD:C_0603_1608Metric | 1
C16 | 100nF | Capacitor_SMD:C_0603_1608Metric | 1
C17 | 10uF | JLC-MCP:C1206 | 1
C18 | 100nF | Capacitor_SMD:C_0603_1608Metric | 1
D2 | SS34 | JLC-MCP:SMA_L4.3-W2.6-LS5.2-RD | 1
D3 | SS34 | JLC-MCP:SMA_L4.3-W2.6-LS5.2-RD | 1
D4 | SS14 | JLC-MCP:SMA_L4.2-W2.6-LS5.0-RD_1 | 1
D5 | SS14 | JLC-MCP:SMA_L4.2-W2.6-LS5.0-RD_1 | 1
D6 | SS14 | JLC-MCP:SMA_L4.2-W2.6-LS5.0-RD_1 | 1
D7 | SS14 | JLC-MCP:SMA_L4.2-W2.6-LS5.0-RD_1 | 1
D8 | SS14 | JLC-MCP:SMA_L4.2-W2.6-LS5.0-RD_1 | 1
D9 | SS14 | JLC-MCP:SMA_L4.2-W2.6-LS5.0-RD_1 | 1
D10 | SS14 | JLC-MCP:SMA_L4.2-W2.6-LS5.0-RD_1 | 1
D11 | SS14 | JLC-MCP:SMA_L4.2-W2.6-LS5.0-RD_1 | 1
D12 | SS14 | JLC-MCP:SMA_L4.2-W2.6-LS5.0-RD_1 | 1
D13 | SS14 | JLC-MCP:SMA_L4.2-W2.6-LS5.0-RD_1 | 1
D14 | SS14 | JLC-MCP:SMA_L4.2-W2.6-LS5.0-RD_1 | 1
D15 | SS14 | JLC-MCP:SMA_L4.2-W2.6-LS5.0-RD_1 | 1
J1 | USB-C PWR | JLC-MCP:USB-C_SMD-TYPE-C-31-M-12_1 | 1
J2 | USB-C | JLC-MCP:TYPE-C-SMD_TYPE-C-6P_1 | 1
J5 | XH-4P | JLC-MCP:CONN-TH_4P-P2.54_6173868 | 1
J6 | XH-4P | JLC-MCP:CONN-TH_4P-P2.54_6173868 | 1
J7 | XH-4P | JLC-MCP:CONN-TH_4P-P2.54_6173868 | 1
J8 | XH-4P | JLC-MCP:CONN-TH_4P-P2.54_6173868 | 1
J9 | XH-4P | JLC-MCP:CONN-TH_4P-P2.54_6173868 | 1
J10 | VALVE | JLC-MCP:CONN-SMD_2P-P2.54_MEGASTAR_ZX-XH2.54-2PWT | 1
J11 | VALVE | JLC-MCP:CONN-SMD_2P-P2.54_MEGASTAR_ZX-XH2.54-2PWT | 1
J12 | VALVE | JLC-MCP:CONN-SMD_2P-P2.54_MEGASTAR_ZX-XH2.54-2PWT | 1
J13 | VALVE | JLC-MCP:CONN-SMD_2P-P2.54_MEGASTAR_ZX-XH2.54-2PWT | 1
J14 | VALVE | JLC-MCP:CONN-SMD_2P-P2.54_MEGASTAR_ZX-XH2.54-2PWT | 1
J15 | VALVE | JLC-MCP:CONN-SMD_2P-P2.54_MEGASTAR_ZX-XH2.54-2PWT | 1
J16 | VALVE | JLC-MCP:CONN-SMD_2P-P2.54_MEGASTAR_ZX-XH2.54-2PWT | 1
J17 | VALVE | JLC-MCP:CONN-SMD_2P-P2.54_MEGASTAR_ZX-XH2.54-2PWT | 1
J18 | DEBUG-UART | JLC-MCP:CONN-TH_4P-P2.54_6173868 | 1
J19 | DEBUG-GPIO | JLC-MCP:CONN-TH_4P-P2.54_6173868 | 1
J20 | VALVE | JLC-MCP:CONN-SMD_2P-P2.54_MEGASTAR_ZX-XH2.54-2PWT | 1
J21 | VALVE | JLC-MCP:CONN-SMD_2P-P2.54_MEGASTAR_ZX-XH2.54-2PWT | 1
J22 | VALVE | JLC-MCP:CONN-SMD_2P-P2.54_MEGASTAR_ZX-XH2.54-2PWT | 1
J23 | PUMP | JLC-MCP:CONN-SMD_2P-P2.54_MEGASTAR_ZX-XH2.54-2PWT | 1
L1 | 6.8uH | JLC-MCP:IND-SMD_L10.2-W10.0 | 1
LED1 | WS2812B | JLC-MCP:LED-SMD_4P-L5.0-W5.0-BL_XL-5050RGBC | 1
LED2 | PWR | JLC-MCP:LED-SMD_L1.6-W0.8-R-RD | 1
LED3 | USER | JLC-MCP:LED0603-RD | 1
LED4 | TX | JLC-MCP:LED0603-RD-YELLOW | 1
LED5 | RX | JLC-MCP:LED0603-RD-YELLOW | 1
Q3 | AO3400A | JLC-MCP:SOT-23-3_L2.9-W1.3-P1.90-LS2.4-BR | 1
Q4 | AO3400A | JLC-MCP:SOT-23-3_L2.9-W1.3-P1.90-LS2.4-BR | 1
Q5 | AO3400A | JLC-MCP:SOT-23-3_L2.9-W1.3-P1.90-LS2.4-BR | 1
Q6 | AO3400A | JLC-MCP:SOT-23-3_L2.9-W1.3-P1.90-LS2.4-BR | 1
Q7 | AO3400A | JLC-MCP:SOT-23-3_L2.9-W1.3-P1.90-LS2.4-BR | 1
Q8 | AO3400A | JLC-MCP:SOT-23-3_L2.9-W1.3-P1.90-LS2.4-BR | 1
Q9 | AO3400A | JLC-MCP:SOT-23-3_L2.9-W1.3-P1.90-LS2.4-BR | 1
Q10 | AO3400A | JLC-MCP:SOT-23-3_L2.9-W1.3-P1.90-LS2.4-BR | 1
Q11 | SS8050 | JLC-MCP:SOT-23-3_L3.0-W1.3-P1.90-LS2.5-BR | 1
Q12 | SS8050 | JLC-MCP:SOT-23-3_L3.0-W1.3-P1.90-LS2.5-BR | 1
Q13 | AO3400A | JLC-MCP:SOT-23-3_L2.9-W1.3-P1.90-LS2.4-BR | 1
Q14 | AO3400A | JLC-MCP:SOT-23-3_L2.9-W1.3-P1.90-LS2.4-BR | 1
Q15 | AO3400A | JLC-MCP:SOT-23-3_L2.9-W1.3-P1.90-LS2.4-BR | 1
Q16 | AO3400A | JLC-MCP:SOT-23-3_L2.9-W1.3-P1.90-LS2.4-BR | 1
R1 | 5.1k | JLC-MCP:R0603 | 1
R2 | 5.1k | JLC-MCP:R0603 | 1
R3 | 100k | JLC-MCP:R0603 | 1
R4 | 10k | JLC-MCP:R0603 | 1
R5 | 3.24k | JLC-MCP:R0603 | 1
R6 | 10k | JLC-MCP:R0603 | 1
R7 | 10k | JLC-MCP:R0603 | 1
R8 | 4.7k | JLC-MCP:R0603 | 1
R9 | 4.7k | JLC-MCP:R0603 | 1
R10 | 1k | JLC-MCP:R0603 | 1
R11 | 1k | JLC-MCP:R0603 | 1
R12 | 330R | JLC-MCP:R0603 | 1
R13 | 10k | JLC-MCP:R0603 | 1
R14 | 10k | JLC-MCP:R0603 | 1
R15 | 10k | JLC-MCP:R0603 | 1
R16 | 10k | JLC-MCP:R0603 | 1
R17 | 22R | JLC-MCP:R0603 | 1
R18 | 22R | JLC-MCP:R0603 | 1
R19 | 1k | JLC-MCP:R0603 | 1
R20 | 1k | JLC-MCP:R0603 | 1
R21 | 10k | JLC-MCP:R0603 | 1
R22 | 10k | JLC-MCP:R0603 | 1
R23 | 1k | JLC-MCP:R0603 | 1
R24 | 1k | JLC-MCP:R0603 | 1
R25 | 1k | JLC-MCP:R0603 | 1
R26 | 1k | JLC-MCP:R0603 | 1
R27 | 10k | JLC-MCP:R0603 | 1
R28 | 10k | JLC-MCP:R0603 | 1
R29 | 10k | JLC-MCP:R0603 | 1
R30 | 10k | JLC-MCP:R0603 | 1
R31 | 10k | JLC-MCP:R0603 | 1
R32 | 10k | JLC-MCP:R0603 | 1
R33 | 10k | JLC-MCP:R0603 | 1
R34 | 10k | JLC-MCP:R0603 | 1
R35 | 10k | JLC-MCP:R0603 | 1
R36 | 10k | JLC-MCP:R0603 | 1
R37 | 10k | JLC-MCP:R0603 | 1
R38 | 10k | JLC-MCP:R0603 | 1
R39 | 1k | JLC-MCP:R0603 | 1
R40 | 1k | JLC-MCP:R0603 | 1
R41 | 1k | JLC-MCP:R0603 | 1
R42 | 1k | JLC-MCP:R0603 | 1
R43 | 1k | JLC-MCP:R0603 | 1
R44 | 1k | JLC-MCP:R0603 | 1
R45 | 1k | JLC-MCP:R0603 | 1
R46 | 1k | JLC-MCP:R0603 | 1
R47 | 10k | JLC-MCP:R0603 | 1
R48 | 10k | JLC-MCP:R0603 | 1
R49 | 10k | JLC-MCP:R0603 | 1
R50 | 10k | JLC-MCP:R0603 | 1
R51 | 10k | JLC-MCP:R0603 | 1
R52 | 10k | JLC-MCP:R0603 | 1
R53 | 10k | JLC-MCP:R0603 | 1
R54 | 10k | JLC-MCP:R0603 | 1
R55 | 1k | JLC-MCP:R0603 | 1
R56 | 1k | JLC-MCP:R0603 | 1
R57 | 1k | JLC-MCP:R0603 | 1
R58 | 1k | JLC-MCP:R0603 | 1
R59 | 10k | JLC-MCP:R0603 | 1
R60 | 10k | JLC-MCP:R0603 | 1
R61 | 10k | JLC-MCP:R0603 | 1
R62 | 10k | JLC-MCP:R0603 | 1
R63 | 5.1k | JLC-MCP:R0603 | 1
R64 | 5.1k | JLC-MCP:R0603 | 1
SW1 | RST | JLC-MCP:SW-SMD_ST-1185S | 1
SW2 | BOOT | JLC-MCP:SW-SMD_ST-1185S | 1
SW3 | USER | JLC-MCP:SW-SMD_ST-1185S | 1
TP1 | +3V3 | TestPoint:TestPoint_Pad_D1.0mm | 1
TP2 | +5V | TestPoint:TestPoint_Pad_D1.0mm | 1
TP3 | GND | TestPoint:TestPoint_Pad_D1.0mm | 1
TP4 | GND | TestPoint:TestPoint_Pad_D1.0mm | 1
TP5 | GND | TestPoint:TestPoint_Pad_D1.0mm | 1
TP6 | GND | TestPoint:TestPoint_Pad_D1.0mm | 1
TP7 | I2C_SDA | TestPoint:TestPoint_Pad_D1.0mm | 1
TP8 | I2C_SCL | TestPoint:TestPoint_Pad_D1.0mm | 1
TP9 | GATE1 | TestPoint:TestPoint_Pad_D1.0mm | 1
TP10 | DRV1 | TestPoint:TestPoint_Pad_D1.0mm | 1
TP11 | PH | TestPoint:TestPoint_Pad_D1.0mm | 1
TP12 | EN | TestPoint:TestPoint_Pad_D1.0mm | 1
TP13 | DRV_PUMP | TestPoint:TestPoint_Pad_D1.0mm | 1
U1 | ESP32-S3-WROOM-1-N16R8 | JLC-MCP:WIRELM-SMD_ESP32-S3-WROOM-1 | 1
U2 | TCA9548APWR | JLC-MCP:TSSOP-24_L7.8-W4.4-P0.65-LS6.4-BL | 1
U3 | TPS54331DR | JLC-MCP:SOIC-8_L5.0-W4.0-P1.27-LS6.0-BL | 1
U4 | CH340K | JLC-MCP:ESOP-10_L4.9-W3.9-P1.00-LS6.2-BL-EP | 1
U5 | USBLC6-2SC6 | JLC-MCP:SOT-23-6_L2.9-W1.6-P0.95-LS2.8-BL | 1
U6 | XGZP6897D | LOCAL:XGZP6897D-SOP8-W7.96-P2.54 | 1
U7 | USBLC6-2SC6 | JLC-MCP:SOT-23-6_L2.9-W1.6-P0.95-LS2.8-BL | 1

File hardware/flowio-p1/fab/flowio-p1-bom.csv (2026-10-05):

LCSC | Value | Footprint | Qty | Refs
C13585 | 10uF | JLC-MCP:C1206 | 3 | C1,C9,C17
C1591 | 100nF | Capacitor_SMD:C_0603_1608Metric | 10 | C2,C5,C6,C10-C13,C15,C16,C18
C33353 | 2.2nF | Capacitor_SMD:C_0603_1608Metric | 1 | C3
C1653 | 22pF | Capacitor_SMD:C_0603_1608Metric | 1 | C4
C15008 | 100uF | JLC-MCP:C1206 | 2 | C7,C8
C15849 | 1uF | Capacitor_SMD:C_0603_1608Metric | 1 | C14
C8678 | SS34 | JLC-MCP:SMA_L4.3-W2.6-LS5.2-RD | 2 | D2,D3
C2480 | SS14 | JLC-MCP:SMA_L4.2-W2.6-LS5.0-RD_1 | 12 | D4-D15
C165948 | USB-C PWR | JLC-MCP:USB-C_SMD-TYPE-C-31-M-12_1 | 1 | J1
C456012 | USB-C | JLC-MCP:TYPE-C-SMD_TYPE-C-6P_1 | 1 | J2
C5359632 | XH-4P | JLC-MCP:CONN-TH_4P-P2.54_6173868 | 5 | J5-J9
C7429671 | VALVE | JLC-MCP:CONN-SMD_2P-P2.54_MEGASTAR_ZX-XH2.54-2PWT | 11 | J10-J17,J20-J22
C5359632 | DEBUG-UART | JLC-MCP:CONN-TH_4P-P2.54_6173868 | 1 | J18
C5359632 | DEBUG-GPIO | JLC-MCP:CONN-TH_4P-P2.54_6173868 | 1 | J19
C7429671 | PUMP | JLC-MCP:CONN-SMD_2P-P2.54_MEGASTAR_ZX-XH2.54-2PWT | 1 | J23
C167253 | 6.8uH | JLC-MCP:IND-SMD_L10.2-W10.0 | 1 | L1
C2843785 | WS2812B | JLC-MCP:LED-SMD_4P-L5.0-W5.0-BL_XL-5050RGBC | 1 | LED1
C2286 | PWR | JLC-MCP:LED-SMD_L1.6-W0.8-R-RD | 1 | LED2
C2288 | USER | JLC-MCP:LED0603-RD | 1 | LED3
C125100 | TX | JLC-MCP:LED0603-RD-YELLOW | 1 | LED4
C125100 | RX | JLC-MCP:LED0603-RD-YELLOW | 1 | LED5
C20917 | AO3400A | JLC-MCP:SOT-23-3_L2.9-W1.3-P1.90-LS2.4-BR | 12 | Q3-Q10,Q13-Q16
C181160 | SS8050 | JLC-MCP:SOT-23-3_L3.0-W1.3-P1.90-LS2.5-BR | 2 | Q11,Q12
C23186 | 5.1k | JLC-MCP:R0603 | 4 | R1,R2,R63,R64
C14675 | 100k | JLC-MCP:R0603 | 1 | R3
C25804 | 10k | JLC-MCP:R0603 | 33 | R4,R6,R7,R13-R16,R21,R22,R27-R38,R47-R54,R59-R62
C22994 | 3.24k | JLC-MCP:R0603 | 1 | R5
C23162 | 4.7k | JLC-MCP:R0603 | 2 | R8,R9
C21190 | 1k | JLC-MCP:R0603 | 20 | R10,R11,R19,R20,R23-R26,R39-R46,R55-R58
C23138 | 330R | JLC-MCP:R0603 | 1 | R12
C23345 | 22R | JLC-MCP:R0603 | 2 | R17,R18
C589191 | RST | JLC-MCP:SW-SMD_ST-1185S | 1 | SW1
C589191 | BOOT | JLC-MCP:SW-SMD_ST-1185S | 1 | SW2
C589191 | USER | JLC-MCP:SW-SMD_ST-1185S | 1 | SW3
 | +3V3 | TestPoint:TestPoint_Pad_D1.0mm | 1 | TP1
 | +5V | TestPoint:TestPoint_Pad_D1.0mm | 1 | TP2
 | GND | TestPoint:TestPoint_Pad_D1.0mm | 4 | TP3-TP6
 | I2C_SDA | TestPoint:TestPoint_Pad_D1.0mm | 1 | TP7
 | I2C_SCL | TestPoint:TestPoint_Pad_D1.0mm | 1 | TP8
 | GATE1 | TestPoint:TestPoint_Pad_D1.0mm | 1 | TP9
 | DRV1 | TestPoint:TestPoint_Pad_D1.0mm | 1 | TP10
 | PH | TestPoint:TestPoint_Pad_D1.0mm | 1 | TP11
 | EN | TestPoint:TestPoint_Pad_D1.0mm | 1 | TP12
 | DRV_PUMP | TestPoint:TestPoint_Pad_D1.0mm | 1 | TP13
C2913202 | ESP32-S3-WROOM-1-N16R8 | JLC-MCP:WIRELM-SMD_ESP32-S3-WROOM-1 | 1 | U1
C130026 | TCA9548APWR | JLC-MCP:TSSOP-24_L7.8-W4.4-P0.65-LS6.4-BL | 1 | U2
C9865 | TPS54331DR | JLC-MCP:SOIC-8_L5.0-W4.0-P1.27-LS6.0-BL | 1 | U3
C968586 | CH340K | JLC-MCP:ESOP-10_L4.9-W3.9-P1.00-LS6.2-BL-EP | 1 | U4
C7519 | USBLC6-2SC6 | JLC-MCP:SOT-23-6_L2.9-W1.6-P0.95-LS2.8-BL | 2 | U5,U7
 | XGZP6897D | LOCAL:XGZP6897D-SOP8-W7.96-P2.54 | 1 | U6

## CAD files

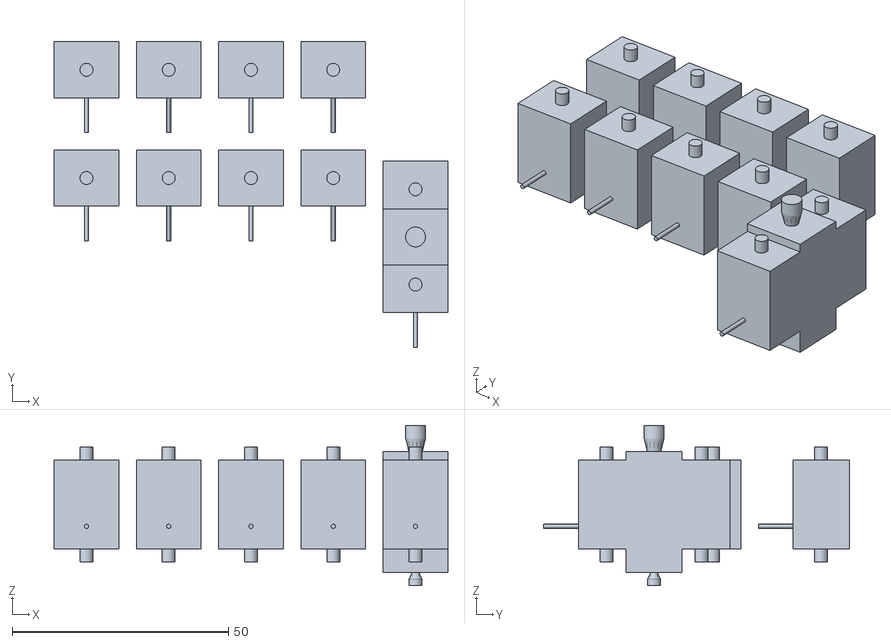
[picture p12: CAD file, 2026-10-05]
firmware/twin/meshes/valves.stl
91.0 x 70.6 x 37.0

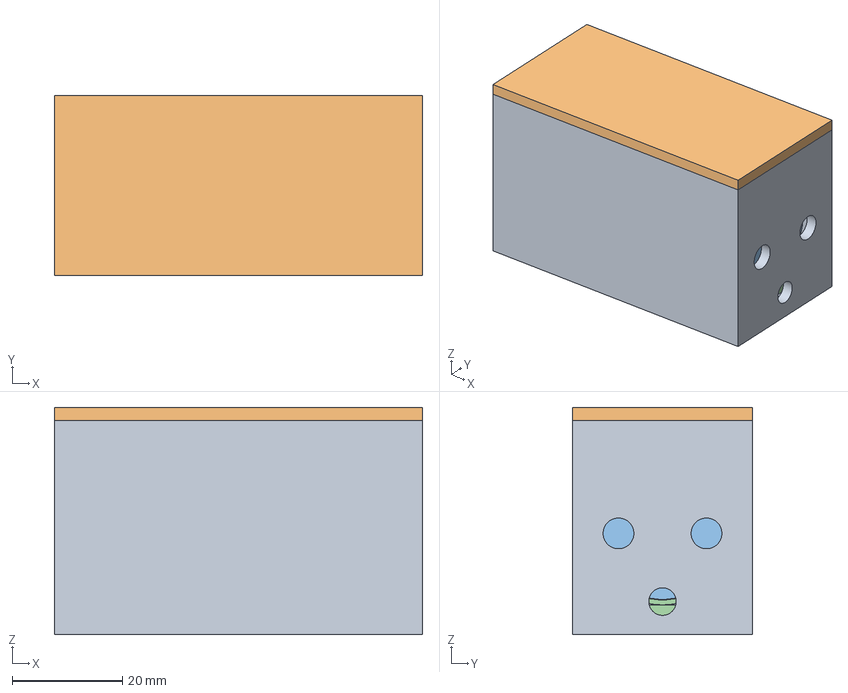
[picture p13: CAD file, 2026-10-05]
hardware/flowio-p1/enclosure/flowio-p1-pump-module.FCStd
66.9 x 32.8 x 41.3 mm
Base
Lid
Pump
Brackets

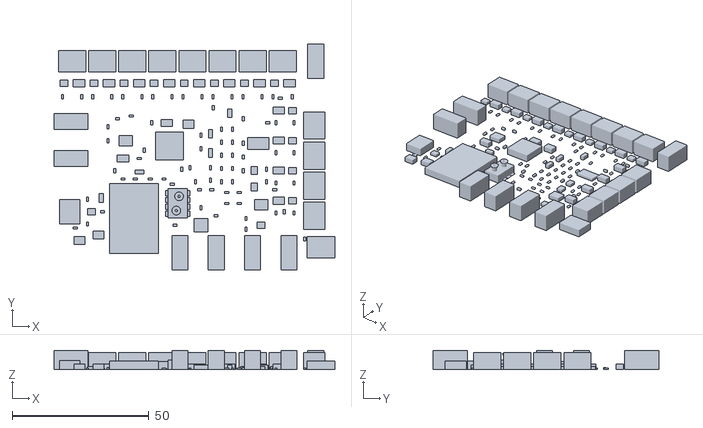
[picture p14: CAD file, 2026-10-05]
firmware/twin/meshes/parts_f.stl
102.8 x 82.5 x 7.00

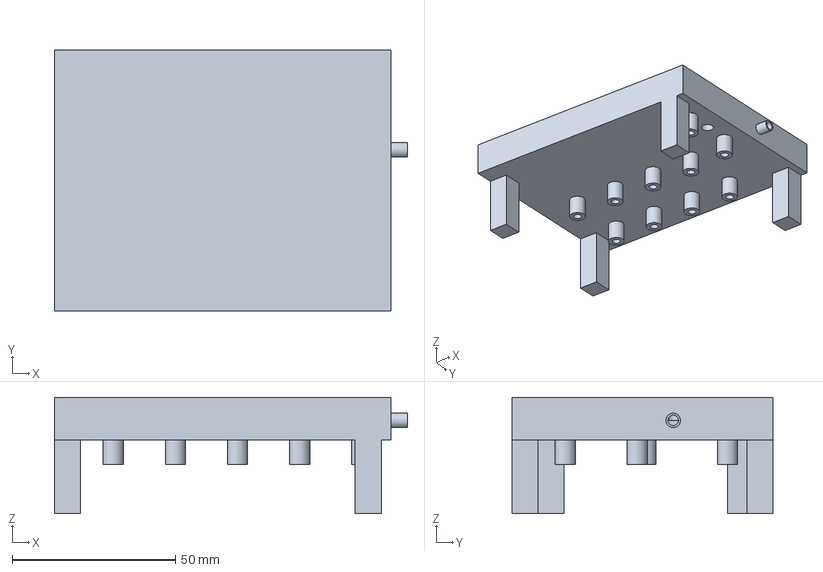
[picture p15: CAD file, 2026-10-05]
hardware/flowio-p1/enclosure/flowio-p1-manifold.FCStd
108.0 x 80.0 x 35.5 mm

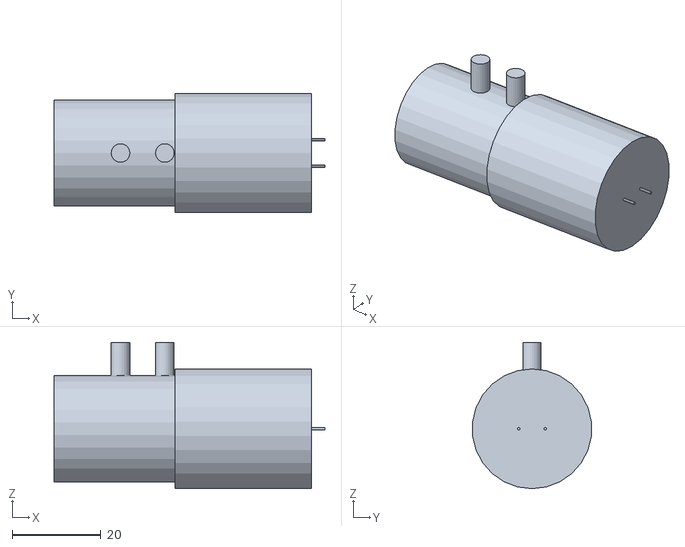
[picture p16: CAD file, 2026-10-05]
firmware/twin/meshes/pump.stl
61.1 x 26.8 x 33.0

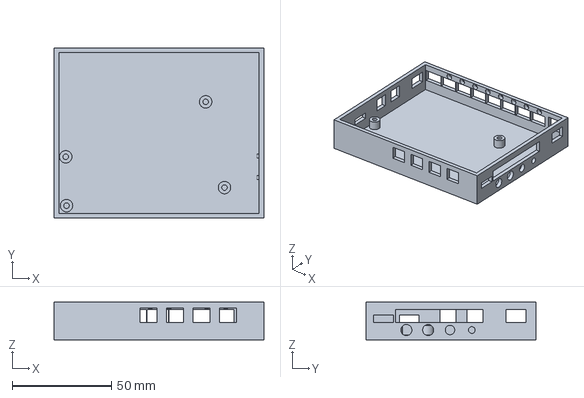
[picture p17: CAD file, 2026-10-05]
hardware/flowio-p1/enclosure/case-bottom.step
105.8 x 85.8 x 19.1 mm

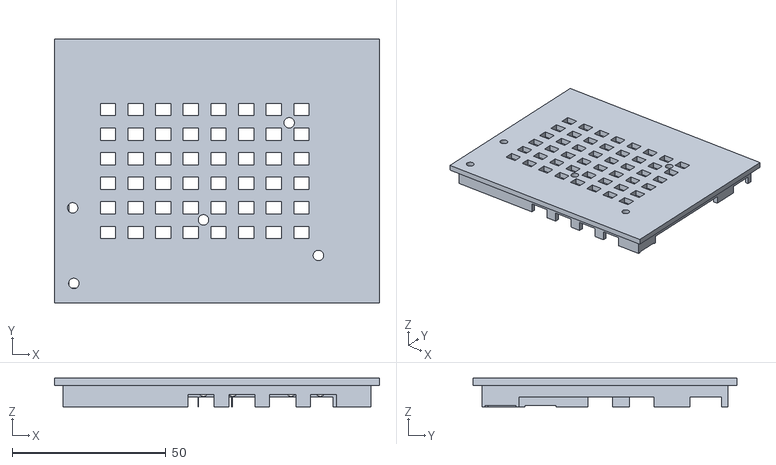
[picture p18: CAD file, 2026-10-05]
firmware/twin/meshes/case_top.stl
105.8 x 85.8 x 9.40

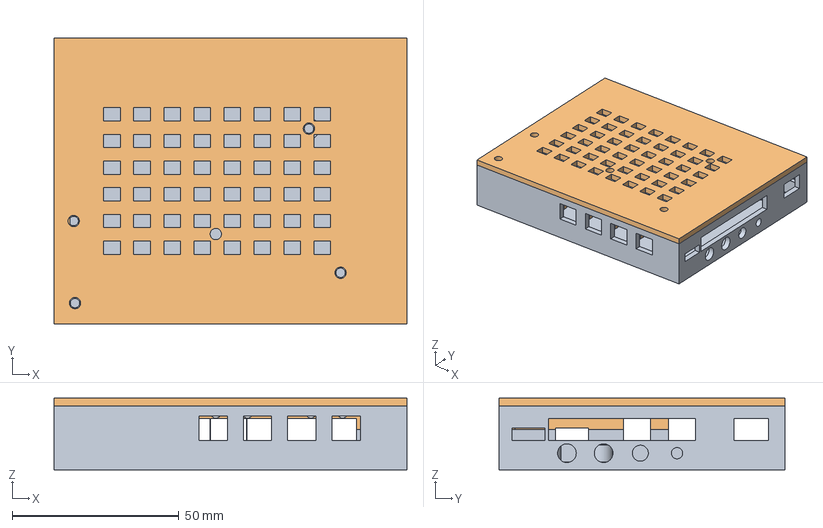
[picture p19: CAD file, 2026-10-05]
hardware/flowio-p1/enclosure/flowio-p1-case.FCStd
105.8 x 85.8 x 21.5 mm
Bottom
Top

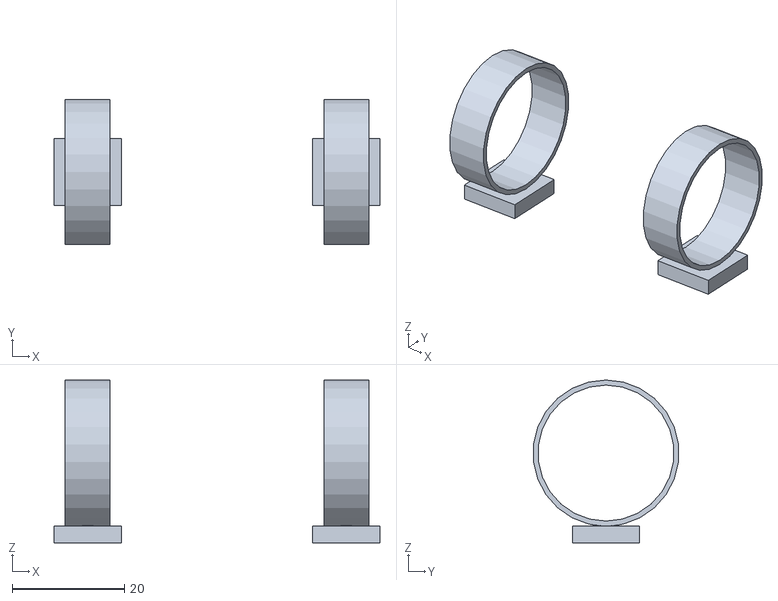
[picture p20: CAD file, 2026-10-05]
firmware/twin/meshes/brackets.stl
58.0 x 25.8 x 29.0

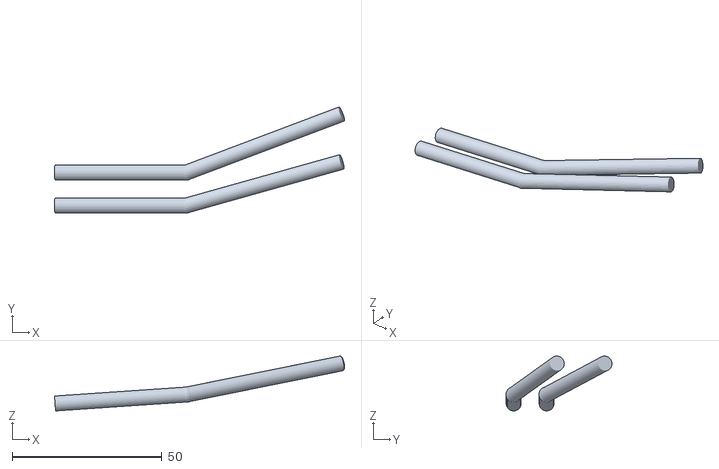
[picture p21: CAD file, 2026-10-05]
site/meshes/tubes.stl
96.9 x 35.4 x 18.3

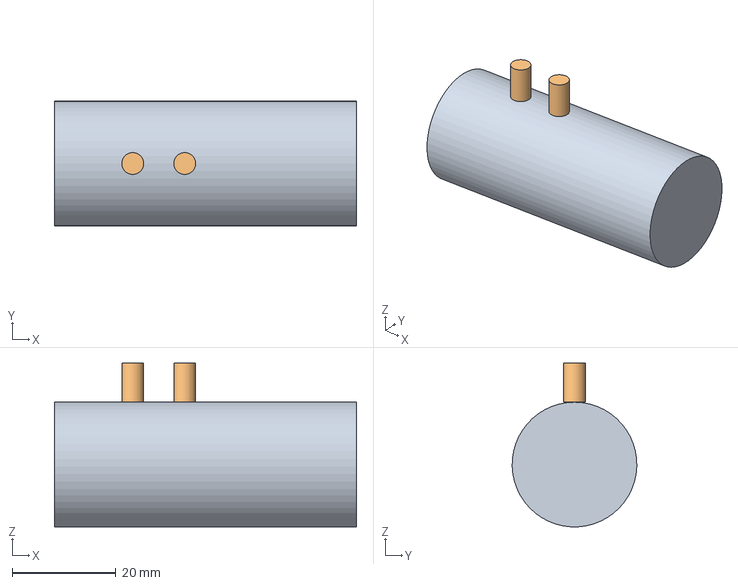
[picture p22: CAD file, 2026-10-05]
hardware/flowio-p1/enclosure/pump.step
58.1 x 24.0 x 31.5 mm

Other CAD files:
site/meshes/case_bottom.stl
hardware/flowio-p1/enclosure/manifold.step
firmware/twin/meshes/case_bottom.stl
firmware/twin/meshes/manifold.stl
firmware/twin/meshes/pcb.stl
firmware/twin/meshes/pump_module.stl
hardware/flowio-p1/enclosure/brackets.step
hardware/flowio-p1/enclosure/case-bottom.stl
hardware/flowio-p1/enclosure/case-top.step
hardware/flowio-p1/enclosure/manifold.stl
hardware/flowio-p1/enclosure/pump-module.step
hardware/flowio-p1/enclosure/pump-module.stl
hardware/flowio-p1/enclosure/pump.stl
site/meshes/manifold.stl
site/meshes/pcb.stl
site/meshes/pump_module.stl

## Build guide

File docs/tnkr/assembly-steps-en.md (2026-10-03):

# FLOWIO-CN Assembly & Bring-Up Steps (EN)

> Derived from `firmware/BRINGUP.md` (9 chapters, 30 checkpoints).
> Each step cites its acceptance ticket (A2xx hardware / A3xx calibration).
> Precondition: JLC-assembled board (5 fab / 2 assembled), bench PSU, ST-Link
> or USB-UART adapter, and a host with ESP-IDF toolchain installed.

## Step 1 — Visual inspection & cold power-rail check (A201)

- [ ] Inspect solder joints under magnification (ICS/QFN pads, connector seating)
- [ ] Measure 3V3-to-GND resistance on the bench PSU rails before any power-up
- [ ] Verify no solder bridges on the buck converter input stage

## Step 2 — Bench supply bring-up at 3.3 V (A202)

- [ ] Current-limited supply on, expect <50 mA idle
- [ ] Scope the buck output ripple (<30 mV pk-pk) — sim reference in `tools/sim/out/`
- [ ] Confirm 5V rail only when valve supply is intentionally enabled

## Step 3 — Program ESP32-S3 via UART (A203)

- [ ] Run `build_n16r8.ps1`; flash via USB-UART
- [ ] Console shows clean boot log, correct partition table, no brownout resets

## Step 4 — I2C bus scan through TCA9548A (A204)

- [ ] Enumerate all 8 mux channels; expected device addresses per channel
- [ ] No NACK storms; pull-up levels within spec

## Step 5 — Sensor readout (A205)

- [ ] Pressure/temperature sensors report plausible values on all channels
- [ ] Cross-check one channel against a reference gauge

## Step 6 — PWM valve-drive sweep (A206)

- [ ] 8-channel duty sweep 0→100%→0; verify monotonic pressure response
- [ ] No cross-talk between channels (neighbor channels at 0%)

## Step 7 — WS2812 status LEDs (A207)

- [ ] Boot pattern, then per-channel state colors; RMT timing stable

## Step 8 — BLE GATT connect + telemetry (A208)

- [ ] Web Bluetooth console connects (Command/Telemetry/Config/DeviceInfo)
- [ ] Live telemetry stream visible in the digital twin

## Step 9 — Closed-loop pressure PID first run (A301)

- [ ] Calibrated setpoints; step response within overshoot budget
- [ ] Log session via twin `record` API for replay

## Step 10 — End-to-end glove profile via SDK + twin replay (A302)

- [ ] Run an inflation/deflation profile from `flowio_sdk`
- [ ] Replay the recorded CSV in the digital twin; curves match live run

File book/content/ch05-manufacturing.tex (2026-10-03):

\chapter{制造：嘉立创全代工实战}
\label{ch:fab}

第~\ref{ch:pcb} 章结束时，P1 板的 DRC 清零、Gerber 交付。但"可制造"与"已制造"之间还隔着一段路：BOM 要带商城编码、贴装坐标要能被 SMT 产线解析、工艺备注要让工人看得懂、费用要能过财务。本章是这段路的完整实录——目标交付形态在 \texttt{README-jlc-order.md} 第一行就写死了：\textbf{用户零手工焊}。嘉立创（JLC）完成 PCB 制造 + 107 件 SMT 贴焊 + 16 件 THT 代插代焊，上下外壳 3D 代打；白牌厂商收货后只需拧 M3 螺丝、插线即用。对 B2B 客户而言，"零焊接门槛"不是便利，是采购决策的一部分——他们的产线上没有回流焊。

为什么坚持全代工而不是"贴片代工 + 插件自焊"的半代工？算三笔账。\textbf{能力账}：16 只插件里有 DC 座、USB-C 座、8 只螺丝端子与 5 只 XH 座，手工焊接的一致性完全依赖工人，而端子排的机械强度直接吃焊接质量——半代工把整板最受力的一批焊点留给了随机性。\textbf{责任账}：单一供应商完成制造 + 贴装 + 插件，出问题时责任边界清晰；半代工的虚焊到底是"板的问题"还是"焊的问题"，扯皮成本远超省下的代插费。\textbf{规模账}：打样 2 片与小批量数百片走同一条标准版工艺路径，转产不需要换产线、换工艺文档——对以"起量"为目标的 B2B 项目，这比单价更重要。

\section{下单资产包：fab/ 目录里都有什么}
\label{sec:fab-assets}

制造输出的全部资产集中在 \texttt{hardware/flowio-p1/fab/}（表~\ref{tab:fab-files}）。每个文件都有明确的上传去向，下单流程里不会出现"临时导出一个文件"的环节——所有产物在布线清零当日一次性生成、打包、核验。

\begin{table}[htbp]
  \centering
  \caption{fab/ 下单资产清单（README-jlc-order \S0）}
  \label{tab:fab-files}
  \begin{tabular}{lp{9.2cm}}
    \toprule
    文件 & 用途 \\
    \midrule
    \texttt{flowio-p1-jlc.zip} & PCB 制造 Gerber 包（下单第一步上传） \\
    \texttt{flowio-p1-bom-jlc.csv} & PCBA 物料清单：38 行 / 123 件，逐行带 LCSC 编码 \\
    \texttt{flowio-p1-pos-jlc.csv} & 贴装坐标（CPL）：首 4 行 \texttt{\#} 注释为核对说明 \\
    \texttt{flowio-p1-pos.csv} & 原版无注释 CPL（上传器报错时的备用，内容与上行一致） \\
    \texttt{assembly-top.pdf} / \texttt{assembly-bottom.pdf} & 上/下贴位置人工核对图 \\
    \texttt{../enclosure/case-top.stl} 等 & 3D 打印上传件（第~\ref{ch:enclosure} 章） \\
    \bottomrule
  \end{tabular}
\end{table}

\section{制板参数与三重验证}
\label{sec:fab-params}

制板参数（表~\ref{tab:fab-params}）按嘉立创经济档能力逐项对齐：0.2/0.2\,mm 最小线宽/间距、0.3\,mm 孔/0.6\,mm 盘的最小过孔（电源孔个别放宽到 0.45/0.9）。两个容易被忽略的选项各有一句理由：\textbf{阻焊过孔覆盖}（Gerber 已做 subtract-soldermask 处理）让过孔不被锡珠桥接，也为后文的 via-in-pad 塞孔打底；\textbf{表面处理选 ENIG}（沉金）而不是喷锡，是为了 XH 插件与端子的可焊性一致性——这是打样包里少数"贵但值"的选项。

\begin{table}[htbp]
  \centering
  \caption{嘉立创打样参数（README-fab）}
  \label{tab:fab-params}
  \begin{tabular}{ll}
    \toprule
    项 & 值 \\
    \midrule
    层数/尺寸 & 4 层 90$\times$75\,mm 矩形 \\
    板厚 & 1.6\,mm \\
    最小线宽/间距 & 0.2/0.2\,mm \\
    最小过孔 & 0.3\,mm 孔 / 0.6\,mm 盘（个别 0.45/0.9 电源孔） \\
    阻焊 & 过孔覆盖（Gerber 已 subtract-soldermask） \\
    表面处理 & ENIG（XH 插件可焊性） \\
    丝印 & 白色 \\
    工艺边 & 无需 \\
    \bottomrule
  \end{tabular}
\end{table}

布线终态的 DRC 记录一并写入 README 供下单前回看：\textbf{未连接 0、error 类 0}，仅剩外观类豁免（丝印压铜/库封装 courtyard 等，详见第~\ref{ch:pcb} 章豁免清单）。交付不是"DRC 过了"一句话，而是\textbf{三重连通性验证}：KiCad DRC + KRT 铜级连图（75 个网络全通，refill 交叉核对一致）+ 天线禁布区 8 点探测零命中。三道验证互为独立实现，任何一道单独放行都不作数——这是本书反复出现的"双轨复核"原则在制造环节的落地。

Gerber 包本身的构成也有核验口径：11 个层文件（F/In1/In2/B.Cu 四铜层 + F/B.Paste + F/B.Silk + F/B.Mask + Edge.Cuts）加 \texttt{.gbrjob}，钻孔 ExCELLon 格式（PTH/NPTH 合并、单位 mm、附 map 图核对）；打包 \texttt{flowio-p1-jlc.zip} 后的三条自检——非 txt 文件数 $=$ 层数文件数 + 钻孔、无 0 字节文件、zip 不超 20\,MB——写在收尾规格书 \S4，属于"上传前 30 秒能做完"的检查，但省掉任何一条都可能换来一轮退单。规格书同时记录了一个显式的"不做"：\textbf{不导出 STEP}——多数封装无 3D 模型（渲染已证实），导出无意义；外壳核对走尺寸图（第~\ref{ch:enclosure} 章）。把"不做的事"和"做的事"一起写进决策记录，是防止后人好心补漏反而引入垃圾产物的办法。

\section{下单七步：从 Gerber 到付款}
\label{sec:fab-steps}

PCBA 下单本身是一个七步流程（jlc.com $\to$ PCB 制造 $\to$ 勾选"PCB 组装"），每一步的核对点见表~\ref{tab:fab-steps}。它看起来琐碎，但每一步都对应一类真实的翻车：参数错档、料不上贴、坐标翻转、工艺未声明、贴装面搞反——每一类都有人付过学费。

\begin{table}[htbp]
  \centering
  \caption{嘉立创 PCBA 下单七步与核对点（README-jlc-order \S1）}
  \label{tab:fab-steps}
  \begin{tabular}{cp{9.6cm}}
    \toprule
    步 & 操作与核对点 \\
    \midrule
    1 & 上传 \texttt{flowio-p1-jlc.zip}，参数照表~\ref{tab:fab-params}（4 层 / 90$\times$75 / 1.6 / 0.2/0.2 / 过孔覆盖 / 白油 / 无工艺边 / ENIG） \\
    2 & 组装类型选\textbf{标准版}（硬约束，见 \S\ref{sec:fab-standard}） \\
    3 & 数量按打样策略填写（\S\ref{sec:fab-cost}） \\
    4 & 上传 BOM，确认解析：38 行全部匹配物料、无"无物料/缺码"行，全部器件勾选上贴 \\
    5 & 上传 CPL，确认解析：123 个位号、全部 top 面；PosY 为负正常（\S\ref{sec:fab-cpl}） \\
    6 & 留言栏抄录工艺备注：via-in-pad 塞孔封帽 + 孔距 0.20 + ENIG（\S\ref{sec:fab-vip}） \\
    7 & 付款前看预览拼版图：顶面 107 SMT + 16 插件全部有位号标注 \\
    \bottomrule
  \end{tabular}
\end{table}

\section{via-in-pad $\times$ 8：塞孔封帽工艺}
\label{sec:fab-vip}

全板有 8 处\textbf{盘内孔}（via-in-pad）：TP1.1、C12.1、LED2.1、U5.2、R24、Q11.2、D10.1、C16.1。它们的成因各不相同（表~\ref{tab:fab-vip}）——去耦电容与测试点的焊盘下借孔换层、USB 串口区的器件密集、+5V 肖特基附近的走线拥挤——但风险是同一个：普通过孔不塞孔，\textbf{回流焊时焊膏会顺着孔桶流走}，焊盘虚焊、器件立碑，而且缺陷藏在器件底下，目检看不见。

\begin{table}[htbp]
  \centering
  \caption{8 处盘内孔清单与器件角色}
  \label{tab:fab-vip}
  \begin{tabular}{llp{5.2cm}}
    \toprule
    焊盘 & 器件 & 角色 \\
    \midrule
    TP1.1 & 测试点 & +3V3 首电测量点（A201 工单） \\
    C12.1 / C16.1 & 0603 电容 & 100\,nF 去耦（电源就近） \\
    LED2.1 & LED & 电源指示灯（PWR） \\
    U5.2 & USBLC6 & USB ESD 保护 \\
    R24 & 1\,k$\Omega$ & 用户指示灯限流电阻 \\
    Q11.2 & SS8050 & 自动下载三极管（GND 脚） \\
    D10.1 & SS14 & +5V 肖特基 \\
    \bottomrule
  \end{tabular}
\end{table}

对策是 IPC-4761 标准的\textbf{树脂塞孔 + 电镀封帽}工艺：孔先用树脂填实，表面镀铜盖平，焊盘恢复成平整平面。打包参数页（README-fab）标注为 Type VII，下单留言栏按 Type VIII（封帽之上再加表面覆盖）抄录——两者在生产端指向同一条"塞孔 + 封帽"产线，名称差异不影响执行，但必须在下单时\textbf{显式声明}，否则产线默认不塞孔，焊膏流入孔桶的虚焊就在所难免。下单留言原文如下，可直接抄录：

\begin{quote}\small
本板 8 处 via-in-pad（TP1.1 / C12.1 / LED2.1 / U5.2 / R24 / Q11.2 / D10.1 / C16.1），需 IPC-4761 Type VIII（树脂塞孔+电镀封帽），否则焊膏流入孔桶造成虚焊；最小孔间距 0.20\,mm（经济档标准支持，如需回到 0.25 请联系改布）；表面处理 ENIG（XH 插件可焊性）。
\end{quote}

另一条工艺备注同样来自布线终态：\texttt{min\_hole\_clearance} 从 0.25 收到 0.20\,mm（经济档标准支持）。README 里特意写了"若需回到 0.25 请告知重布"——把可回退的余地留给产线，比硬顶参数下单后被退单更省一轮时间。

\section{BOM 的单一真值源：make\_bom.py 与 LCSC 编码}
\label{sec:fab-bom}

BOM 不是从原理图工具里"导出"的，而是从\textbf{代码生成的真值源}里"再生成"的。P1 的原理图本身由 \texttt{gen\_sch.py} 生成（第~\ref{ch:schematic} 章），其中 \texttt{PARTS} 列表是全板元件的唯一事实：每颗料以 \texttt{P(ref, sym, val, fp, lcsc, x, y, nets)} 七元组喂入——\texttt{lcsc} 字段在选型时就回填好商城编码，BOM 生成时零查询、零手工。\texttt{make\_bom.py} 的工作是把这份真值源变成 JLC 上传格式，全程纯标准库：

\begin{lstlisting}[language=Python, basicstyle=\small\ttfamily, breaklines=true,
  caption={make\_bom.py 核心：受限解析、分组合行、覆盖率与交叉验证（摘编）}]
# 受限 ast 解释器: 只允许 P() 调用 + 字面量/名/下标/算术/f-string,
# 覆盖 gen_sch.py 里 PARTS 的三种喂料方式: 顶层 += 列表 / for-append / for-+=
# (禁 exec —— 生成下单文件时不执行任何原理图代码)

placed  = [p for p in PARTS if p["lcsc"]]   # 有码 -> 可上贴
# 分组键: (lcsc, footprint, value) —— 同码同封装同值合一行
for p in placed:
    groups.setdefault((p["lcsc"], p["fp"], p["val"]), []).append(p["ref"])

def mpn_of(pt):
    """sym 字段清洗成 MPN: 去掉 JLC 库命名尾缀 _Cxxxxxx / 悬空下划线"""
    return re.sub(r"_C\d+$", "", pt["sym"] or "").rstrip("_")

rows.sort(key=lambda r: (r["tht"], ref_key(r["refs"][0])))  # SMT 在前, ref 自然序
# ……写出 flowio-p1-bom-jlc.csv (Comment,Designator,Footprint,LCSC Part #) ……

print(f"SMT LCSC 码覆盖率: {sum(1 for p in placed if not is_tht(p['fp']))}/{n_smt} = 100%"
      if all(p['lcsc'] for p in placed if not is_tht(p['fp'])) else "SMT 存在缺码!")
# 交叉验证: BOM 位号集合 == CPL 位号集合 (TP/HA-HD 等无器件孔除外)
if not only_pos and not only_bom:
    print(f"交叉验证: BOM {len(bom_refs)} refs == CPL {len(pos_refs)} refs, 一致")
\end{lstlisting}

四个设计点值得展开。\textbf{其一，受限 ast 解释器}：解析 \texttt{PARTS} 时只允许 \texttt{P()} 调用与字面量运算（禁 \texttt{exec}），与 \texttt{gen\_pcb.py} 同一模式——生成下单文件的动作不执行任何原理图代码，供应链工具链不做代码执行。解释器覆盖 \texttt{PARTS} 的三种喂料写法：顶层 \texttt{+=} 列表、\texttt{for} 循环 \texttt{append}、\texttt{for} 循环增量累加——真值源怎么组织是原理图的自由，解析器全接得住；遇到不支持的语法节点立即报错退出，绝不静默漏料。\textbf{其二，分组合行}：以 (LCSC 码, 封装, 值) 为键合并同类料，123 件收敛为 38 行，行序 SMT 在前、同组位号自然数排序（\texttt{C1,C2,\dots,C16} 而不是字典序的 \texttt{C1,C10,C11}）；表~\ref{tab:fab-bom} 是成品 BOM 的头部几行。\textbf{其三，LCSC 编码回填}：编码不是 BOM 阶段补的，而是选型阶段随 \texttt{P()} 调用逐颗回填进真值源，\texttt{sym} 字段里的 JLC 库命名尾缀（\texttt{\_C8678} 之类）在 \texttt{mpn\_of} 里清洗成干净的 MPN——"设计即含供应链信息"，这是全代工流程能全自动的原因。\textbf{其四，自检兜底}：SMT 与 THT 的 LCSC 覆盖率分别断言 100\%，BOM 与 CPL 位号集合交叉验证必须相等（\texttt{pos} 有而 \texttt{BOM} 无、\texttt{BOM} 有而 \texttt{pos} 无，两个方向的差集都必须为空）；无码器件（测试点 TP1--TP12 是裸铜焊盘、安装孔 HA--HD 是板件孔）明确打印"不入 BOM"，产线不会看到来路不明的空行。

\begin{table}[htbp]
  \centering
  \caption{成品 BOM 头部（flowio-p1-bom-jlc.csv，节选）}
  \label{tab:fab-bom}
  \begin{tabular}{llll}
    \toprule
    Comment & Designator & Footprint & LCSC \\
    \midrule
    CL10B104KB8NNNC & C2,C5,C6,C10--C13,C15,C16 & C\_0603 & C1591 \\
    SS34 & D1,D2,D3 & SMA & C8678 \\
    SS14 & D4--D11 & SMA & C2480 \\
    TYPE-C\_6P & J2 & TYPE-C-SMD & C456012 \\
    ESP32-S3-WROOM-1 & U1 & SMD 18$\times$25.5 & C2913202 \\
    \bottomrule
  \end{tabular}
\end{table}

价格口径顺带一提：全板最贵单件 U1（ESP32-S3-WROOM-1-N16R8）在规格书记录为 5.14 元、下单页实时价一度约 26 元——LCSC 编码锁定的是\textbf{物料身份}，价格以下单页实时价为准，预算区间里已留了余量。

\section{供应链实拍：国产平替的 B2B 叙事}
\label{sec:fab-supply}

BOM 上的 38 行料号最终要变成一箱到手的实物。下单同期的采购调研留下一组实物照片（存档 \texttt{资源/实物图/}：厂商 Listing 图 18 张、散件清点照 9 张，另有散件清单 PDF 存档于 \texttt{资源/器件规格书/}），给"国产 BOM"这个差异化卖点补上了实物注脚。图~\ref{fig:fab-handes} 是汉戴斯——B2B 平台上的气动器件供应商——Listing 页的实物图：0520 系列阀、微型泵与快插接头在这个生态里是\textbf{现货工业品}而非定制件。这正是白牌供应链的底色：执行器与气路器件早已被国产气动产业标准化，行业真正缺的是可靠的驱动与控制层——FLOWIO-CN 补的就是这一层。

\begin{figure}[htbp]
  \centering
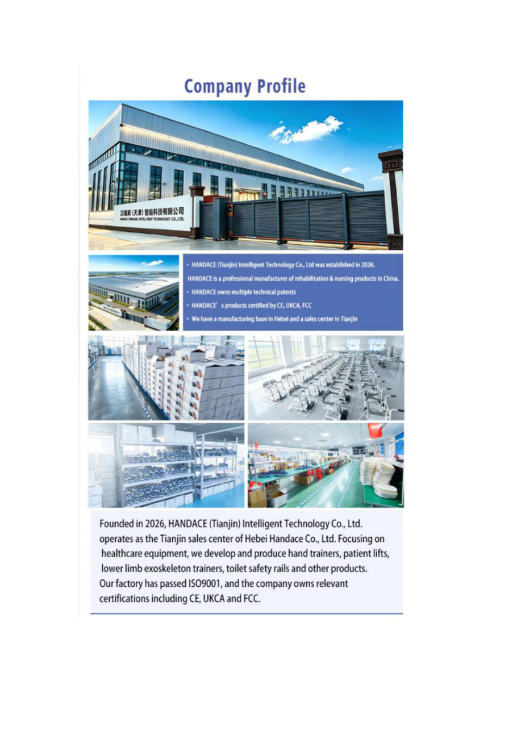
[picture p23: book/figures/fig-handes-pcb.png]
  
  \caption{气动器件供应商（汉戴斯）Listing 实物图——0520 系列阀/微型泵/接头类器件在 B2B 平台现货供应（图源：采购调研存档，\texttt{资源/实物图/handes\_p2.png}；18 张系列图存档同目录）}\label{fig:fab-handes}
\end{figure}

散件清点照则是收货侧的对照工具：到货批次按清点照与 BOM 逐项核对，避免"贴装缺件"与"采购漏件"两类事故在上线当天才暴露。对 B2B 客户，"国产 BOM"的完整含义由此拆成三件可验证的事：\textbf{器件现货}（本节实拍）、\textbf{全代工制造}（本章下单实录）、\textbf{平替有据}（0520D/F 与 XGZP 的规格书级对照，第~\ref{ch:pneu-theory} 章）——三者合起来，才是"供应链交付"而非"料单交付"。

\section{标准版是硬约束，不是省钱选项}
\label{sec:fab-standard}

PCBA 下单第二步要选组装类型：经济版或标准版。对这个决定，README 的措辞罕见地斩钉截铁——"不是省钱问题，是硬约束"，理由有二：

\begin{itemize}
  \item \textbf{U1 卡死经济版}：ESP32-S3-WROOM-1-N16R8（C2913202）在 JLC 元件库的属性是 \texttt{standard-only}——经济版产线无法上贴这颗料。这不是传闻，是实测查询确认的库属性。
  \item \textbf{THT 只有标准版代插代焊}：J1（DC 座）+ J5--J9/J18/J19/J10--J17 共 16 只插件，只有标准版提供代插代焊。这 16 个孔位器件正是"零手工焊"的关键——经济版下单意味着 16 只连接器全部手工焊接，白牌客户的产线门槛立刻回来了。
\end{itemize}

页面若出现"经济型 + 代插件"之类的组合选项也不行——U1 那一条就先卡死。所以标准版不是在两档价格里挑了贵的一档，而是\textbf{唯一的可行档}。这个结论写进下单指南的目的，是防止后来者在下单页看到价差时"优化"掉这个决定。

顺带厘清一对容易混淆的概念：\textbf{经济档与标准版说的是两件事}。"经济档"指制板工艺档位（最小线宽/间距 0.2/0.2\,mm、过孔 0.3/0.6\,mm 这些能力边界，P1 的设计规则全程对齐它，个别 0.15\,mm 细线只在布线攻坚时作为最后手段用于 6 条 $<$10\,mm 补线）；"标准版"指贴装服务档位（哪些料能上贴、能否代插 THT）。P1 的选择是"制板按经济档能力设计 + 贴装必须标准版"——两头各取所需，互不矛盾。

\begin{table}[htbp]
  \centering
  \caption{经济版 vs 标准版（P1 视角）}
  \label{tab:fab-tiers}
  \begin{tabular}{lp{4.5cm}p{4.5cm}}
    \toprule
    维度 & 经济版 & 标准版（P1 选用） \\
    \midrule
    元件库范围 & 基础库 + 扩展库（经济档） & 全库，含 \texttt{standard-only} 料 \\
    U1（C2913202） & \textbf{不可上贴} & 可上贴 \\
    THT 代插代焊 & 无（或受限组合） & 16 只插件全代焊 \\
    费用 & 低 & 高（工程费+钢网+上料） \\
    对 P1 的意义 & 仅制板工艺档可用 & "零手工焊"的唯一路径 \\
    \bottomrule
  \end{tabular}
\end{table}

\section{板 5 装 2 与费用区间}
\label{sec:fab-cost}

打样数量的最终策略是\textbf{板 5 装 2}：PCB 制造 5 片（制板起订最低量），贴装只做 2 片（主力 + 备用）。取舍逻辑很直白——打样阶段真正的风险集中在首块贴装板上，多贴三片救不了系统性缺陷，却把物料费翻倍；多出的 3 片裸板留着作补焊与改制实验的板材。费用区间按两个口径记录（表~\ref{tab:fab-cost}）：全贴 5 片的完整估算（README 记录，约 550--1150 元），与板 5 装 2 策略的执行口径（约 360--720 元，HANDOFF 记录值）——差额主要来自按片计费的贴装与物料。

\begin{table}[htbp]
  \centering
  \caption{打样费用区间（元，不含运费；上行 README 全贴 5 片估算，末行 HANDOFF 板 5 装 2 记录）}
  \label{tab:fab-cost}
  \begin{tabular}{ll}
    \toprule
    项 & 区间 \\
    \midrule
    PCB（4 层 90$\times$75 $\times$ 5，ENIG） & $\sim$50--100 \\
    标准版贴装（工程费+钢网+上料+THT 代插） & $\sim$300--600 \\
    元器件物料 & $\sim$150--300（5 套） \\
    3D 打印（两外壳） & $\sim$50--150 \\
    \midrule
    合计（全贴 5 片） & \textbf{$\sim$550--1150} \\
    合计（板 5 装 2） & \textbf{$\sim$360--720} \\
    \bottomrule
  \end{tabular}
\end{table}

对照第~\ref{ch:intro} 章的售价定位：单套打样全成本落在数百元区间，与"套件售价 300--500 元 + 白牌厂商的执行器/织物成本"的 B2B 定价结构是自洽的——制造端没有结构性亏损点。

自购清单同样为零：BOM 内 123 件全部由 JLC 供料上贴或代插，不存在"自购不上贴"项。需要自备的只是使用耗材——XH2.54-4P 对线、USB-C 数据线、DC 5V/3A 适配器、气路快插接头与气管、装壳的 M3$\times$6 螺丝 4 颗。

\section{CPL 坐标与人工核对}
\label{sec:fab-cpl}

贴装坐标文件（CPL）是产线的"放料地图"，出错即批量错位。P1 的 CPL 有三个实操细节。其一，PosY 为负值——这是 KiCad 向下 y 轴的导出方向，JLC 直接接受，无需翻转；与其花时间在导出器里翻轴，不如把这个事实写进注释让核对者安心。其二，\texttt{-jlc} 版在文件头加了 4 行 \texttt{\#} 注释说明核对方法，若上传器报表头错误，删注释行再传——原版 \texttt{flowio-p1-pos.csv} 内容完全一致，作为无注释备份保留在同级目录。一份数据、两个文件版本，是用"冗余"换"上传器兼容性"的廉价保险。其三，也是最重要的——\textbf{机器解析通过不等于坐标正确}：上传器只校验格式，不校验语义；必须人工抽检，任取 3 行对照 \texttt{assembly-top.pdf}，核对法为 U1 应在板左上、J10--J17 应在板底边一排、J2 应在板右上角。三个锚点分别覆盖"大件 BGA 类""多件端子排""小件连接器"三种易错形态。位号共 123 个、全部 top 面；付款前再看一眼预览拼版图：顶面 107 SMT + 16 插件全部有位号标注，即可下单。

\section{收货验收：从目检到上电}
\label{sec:fab-receive}

收货后的验收三步走，写在下单指南末尾、与回板工单衔接（A201 首电三测等，见第~\ref{ch:acceptance} 章）：

\begin{enumerate}
  \item \textbf{目检}：U1 模组四侧焊脚、J10--J17 端子无歪斜/浮高、XH 座无损脚——插件工序的缺陷在这一步最容易被肉眼发现；
  \item \textbf{上电}（DC 座或 USB 供电）：TP2 测 $+5$\,V、TP1 测 $+3.3$\,V、LED2（PWR）亮——三个测试点就是第~\ref{ch:pcb} 章布线时特意保留的裸铜焊盘；
  \item \textbf{外壳试装}：PCB 入下壳、四角 M3 孔对位（HA--HD）、上壳按键对准 SW1/SW2/SW3——结构对位的最后确认（第~\ref{ch:enclosure} 章）。
\end{enumerate}

三步全过，制造闭环完成；任何一步失败，证据（照片/万用表读数）按工单机制回流到书稿（第~\ref{ch:acceptance} 章的"踩坑实录"专栏——fail 的工单同样入书）。

\section{制造交付的完成定义}
\label{sec:fab-done}

"可以下单了"不是一个感觉，而是一张可勾选的门槛表。收尾规格书 \S1 为制造交付定义了六条验收门槛（表~\ref{tab:fab-gate}），其中"目视检查"一行值得强调：它被用户定为\textbf{强制要求}——修复后重新渲染顶/底两视图逐区人工检查。第~\ref{ch:pcb} 章天线禁布区那场"自动布线器静默删约束"的事故，正是这条铁律的直接理由。

\begin{table}[htbp]
  \centering
  \caption{制造交付验收门槛（收尾规格书 \S1）}
  \label{tab:fab-gate}
  \begin{tabular}{lp{8.2cm}}
    \toprule
    验收项 & 门槛 \\
    \midrule
    DRC error 类 & \textbf{0}（未连接/间距/孔间距全清零） \\
    悬空过孔 & 0 \\
    外观类 & 豁免清单记录在案（JLC 可制，见第~\ref{ch:pcb} 章） \\
    制造输出 & Gerber + 钻孔 + 坐标 + BOM + 装配 PDF，JLC 参数核对通过 \\
    外壳 & 参数化源文件 + 渲染 STL，四铜柱位与最终 HD 孔位一致 \\
    目视检查 & 顶/底两视图渲染逐区人工检查（用户强制要求） \\
    \bottomrule
  \end{tabular}
\end{table}

六条门槛的共同点：每一条都有\textbf{机器可复查的产物}——DRC 报告、豁免清单、下单 zip、外壳脚本与渲染图。后人接手时不必信任任何人的记忆，重跑一遍工具链即可验证。这就是"制造输出"与"制造完成"的区别：前者是文件，后者是文件加证据。

把本章散落各节的翻车点汇成一张速查表（表~\ref{tab:fab-fail}）——每一行都来自本项目真实踩过或真实核实过的风险，不是想象出来的清单。

\begin{table}[htbp]
  \centering
  \caption{下单失败模式速查（症状 $\to$ 根因 $\to$ 预防）}
  \label{tab:fab-fail}
  \begin{tabular}{lp{4.2cm}p{4.2cm}}
    \toprule
    症状 & 根因 & 预防 \\
    \midrule
    BOM 有行"无物料/缺码" & 选型时未回填 LCSC 码 & 覆盖率 100\% 断言；缺码即中止生成 \\
    部分器件未上贴 & BOM 解析后未勾选 & 逐项确认"经济+免经济"全部勾选 \\
    CPL 上传器报表头错误 & \texttt{\#} 注释行不被解析 & 删注释行重传；无注释备份件常备 \\
    坐标镜像/翻转 & 误改 PosY 符号 & 三锚点人工抽检（U1/J10--J17/J2） \\
    via-in-pad 虚焊 & 未声明塞孔工艺 & 留言栏显式抄录 Type VIII 要求 \\
    U1 无法上贴 & 误选经济版 & 标准版是硬约束（\S\ref{sec:fab-standard}） \\
    外壳支撑过剩 & 打印方向被自动重排 & "摆件需人工确认"+备注原始方向 \\
    \bottomrule
  \end{tabular}
\end{table}

\section*{本章小结}
制造环节的全部输出都是\textbf{可复现的文件}而非人工操作：BOM 从 gen\_sch.py 的 PARTS 真值源再生成，LCSC 编码在选型时逐颗回填，受限解析器保证生成过程不执行原理图代码；8 处 via-in-pad 的塞孔封帽与 0.20\,mm 孔距作为工艺备注写进下单留言；标准版组装是 U1 库属性与 16 只 THT 共同决定的硬约束；板 5 装 2 把打样成本压到约 360--720 元。收货三步验收之后，"可制造"终于变成"已制造"——接下来的问题是给它一个家。

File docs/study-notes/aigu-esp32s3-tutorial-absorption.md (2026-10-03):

# 艾谷科技 ESP32-S3 入门教程资料吸收笔记

> 来源: `E:/FLOWIO-外部参考/_ref/【艾谷科技】ESP32S3入门视频教程资料`
> 阅读日期: 2026-10-02 · 读者: 项目主脑 · 目的: 与 P1 板/固件设计交叉验证，提取增量价值

---

## 1. 资料全景

| 目录 | 内容 | 与本项目相关度 |
|---|---|---|
| 0 资料 | 乐鑫官方 PDF 全家桶（S3 datasheet/技术参考手册/**勘误表 errata**/硬件设计指南/产测指南，均中文版） | **高**——比英文版快读；errata 与硬件设计指南是 P1 回板前排障首选 |
| 1 原理图 | 底板+核心板 PDF 原理图（同款 N16R8 模组） | 中——我们的 P1 原理图已定稿，作对照审图参考 |
| 4_Program (v5.5.4) | 24 个 IDF 示例工程（LED→PWM→ADC→I2C→UART→SPI→Camera→WIFI STA/AP→NTP→**BLE NimBLE**→FreeRTOS/GPTimer/分区表） | **高**——25_BLE 是与我们 S5 同栈的最小可用参照 |
| 8 课件 PPT | 198 页课程主线（芯片→模组→Strapping→FreeRTOS→外设→文件系统→分区表→WIFI/BLE） | 中——概念框架与我们设计交叉验证 |
| 3/5/6/7 | 接线图/模块资料/SD 图片/示例图 | 低（教学套件向） |

注: 资料加密压缩包解压密码 `Aigo`（解压密码.txt）。

## 2. 与 P1 设计的交叉验证（结论：无冲突，三处已印证）

### 2.1 Strapping 引脚三件套 ✅ 已正确处理
PPT slide 23-24 确认 S3 strapping 语义：**GPIO0+46 定启动模式**（0+0=Download 其余 SPI Boot）、GPIO3=JTAG 源选择、GPIO45=VDD_SPI 电压。板级审计（实跑 pcbnew 查 U1 焊盘网络）：

| 网络名 | U1 焊盘 | 板上处置 | 判定 |
|---|---|---|---|
| STRAP3 | 15 | R14 10k 上拉 +3V3（JTAG 源=默认） | ✅ |
| STRAP45 | 26 | R15 10k 下拉 GND（VDD_SPI=3.3V） | ✅ |
| STRAP46 | 16 | R16 10k 上拉 +3V3（配 GPIO0=SPI Boot） | ✅ |

且阀栅极网络（IO4/5/6/7/10/11/12/21）**零触碰 strapping 引脚**——教程强调的"Strapping 引脚上电被采样、外设强驱动会打架"风险我们不存在。GPIO0 走 CH340 DTR/RTS 自动复位链（spec 引脚表既有），main.c 注释也已写明"复位瞬间不要按 BOOT"。

### 2.2 BLE NimBLE 最小实现 ✅ 与我们 S5 同构
25_BLE 示例（myble.c, 166 行）验证了我们 ble_twin.c 的骨架选型：`nimble_port_init → svc_gap/gatt_init → ble_gatts_count_cfg/add_svcs → sync_cb 里 start_advertising → host_task 跑 nimble_port_run`，GAP 事件里**断连自动重启广播**（我们的实现同样处理）。差异点（我们更完整）：教程用 16bit UUID+单服务双特征；我们按 BLE.md 用 128bit 自有命名空间+四服务+20B 二进制 state notify+cmd 队列解耦。**无新增风险项**。

### 2.3 sdkconfig/分区表 ✅
我们 Flash 16MB（FLASSIZE_16MB=y）N16R8 与教程套件同规格；分区表/FreeRTOS 章节概念与我们 qemu_smoke/build 流程一致。

## 3. 增量价值提取（三件，已列行动）

### V1: 勘误表必读（回板前排障金矿）★
`0 资料/esp32-s3_errata_cn.pdf`——P1 用 S3 的 I2C/LEDC/RMT/USB-Serial-JTAG 全在 errata 覆盖面内。**行动**：BRINGUP.md 第 0 步之前加"通读 errata 与硬件设计指南的 I2C 时序/USB 布线章节"（已作为待办记入本文 §4）。

### V2: 硬件设计指南中文版——PCB 复盘对照
`esp32-s3_hardware_design_guidelines_cn.pdf` 可对 P1 做一次"事后 DFX 审查"：电源滤波电容位置/天线净空（我们已有 6.4mm）/USB 差分/晶振布局。P1 已打样待回，**若首板有射频/电源问题，此文档是第一排查手册**。

### V3: WIFI STA/AP + NTP 示例——路线图 OTA 的垫脚石
22/23/24 号工程（STA 连网/AP 热点/NTP 对时）是"路线图 OTA 升级"的最短前置链：到时直接以其为模板写 wifi 管理 + HTTPS OTA，不必从零搭。

## 4. 待办落账

- [x] ~~`firmware/BRINGUP.md` 步骤 0 前插入"读 errata_cn.pdf（I2C/LEDC/USB-JTAG 章节）+ hardware_design_guidelines_cn.pdf（天线净空/USB 差分章节）"~~ **已完成（2026-10-01 裁定落地）**：前置阅读两项已入书稿——ch11 BRINGUP 动线案头前置 + ch12（书稿第 14 章）校准前置阅读清单，并接 \cite{esp32s3-errata-cn,esp32s3-hw-guidelines-cn}（bib 键 esp32s3-errata-cn / esp32s3-hw-guidelines-cn）；`firmware/BRINGUP.md` 本体一行改动随下次固件侧提交顺带
- [ ] 路线图 OTA 启动时：模板 = 22_WIFI_STA + 24_NTCTime + idf `esp_https_ota`
- [ ] 资料保留在项目树外（`E:/FLOWIO-外部参考/`），不 git 入库（Mimosa 纪律）

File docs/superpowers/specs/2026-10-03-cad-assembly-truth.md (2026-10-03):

# Spec: CAD 装配逻辑统一 + CAD 测试体系（用户报障：爆炸视图装配结果错误）

> 日期: 2026-10-03 · 分支: fix-cad-assembly · 状态: 已执行
> 触发: 用户在生产站 (gh-pages) 发现爆炸视图装配结果错误，并指出"原理图/PCB/固件/孪生有单元/接口/功能测试，CAD 没有"。

## 1. 诊断结论（程序取证，非目测）

### 1.1 四个生成源 z 基准互相矛盾（核心病根）

机械真相只有一个：**M3 螺丝穿 PCB 孔自攻入铜柱 → 板必须坐在铜柱顶 z = WALL+PH = 7.4**。

| 文件 | 板底 z | 判定 |
|---|---|---|
| make_case.py | 注释"Z0=2.4 板底面所在"，但铜柱物理顶到 7.4；内腔高/侧槽带全按 2.4 设计 | **自相矛盾** |
| make_meshes.py（孪生 STL/assembly.json 数据源） | 2.4（板趴腔底，被铜柱穿透） | 错 |
| make_flows.py（hotspots/flows） | Z_TOP=4.0 | 错 |
| make_assembly.py（557 实体 STEP） | 7.4 | z 对，但断言过松（±2.5） |

### 1.2 上壳根本不是盖子（第二病根）

`top_cavity` 从 z=2.8 才起挖 → "顶盖"保留了 z 0..2.8 的**完整底板** + 全高四壁 = 一个带底的方盒：
- case_top.stl 3020 个三角形中 2996 个堆在 z<5（程序直方图取证）；
- 与 case_bottom 同占 z 0..19、几乎完全互相穿插（装配视图双底板/同位墙壁）；
- 通风栅刻在"底板"上 = 盖子做反了。

### 1.3 连锁错误

- 外壳总高 19.0 装不下真实装配栈：板顶 9.0 + 端子 11.0 = 20.0 > 内腔顶 19.0（盖不上盖）。
- parts_b.stl 为 84 字节空文件，但 assembly.json 仍列"器件阵-底面"（BOM 无底面器件）。
- hotspots.json z 全按旧板顶 4.0 计算。
- make_assembly.py `Y_FLIP` 双分支从未验证（注释自承"预览若端子排未贴底边改 False 重跑"）。

### 1.4 已验证的黄金事实（修复的地基）

- 坐标映射 `x=PosX, y=−PosY(+OX)`：J10(6.5,68.5)/J2(86,6)/J1(5.5,27) 三锚点断言通过（make_meshes.verify_mapping）。
- 铜柱 ST 与钻孔文件 T9（NPTH 3.2）四孔 **Δ=0.00**。
- 底边端子 J10..J17 = 8×2P 恰对应 TERM_X 8 槽；J1(DC005,板边外伸2.3mm)⊂L@27 槽、J2(TYPE-C,外伸1.15)⊂R@6 槽、4P 端子 J5-J9/J18/J19 ⊂ L/R/T 槽——**槽位 XY 全部吻合，只有 Z 带需重定基准**。
- KiCad PCB STEP：Y∈[−75,0]，555 实体（过滤 136 离群后）。

## 2. 统一装配栈（唯一真相，case_geom.py 单一来源）

```
WALL=2.4 CLR=0.5 OX=2.9 · 板 90×75×1.6 · OW×OH=95.8×80.8
Z_FLOOR=2.4（腔底） → 铜柱 2.4..7.4（PD=2.8 M3自攻底孔, OD=6.3） → 板 7.4..9.0
→ 器件基面 Z_TOP=9.0 → 最高件端子 11.0 → 内腔顶 Z_CEIL=20.6 → 总高 OUTER_H=23.0
顶盖 = 裙边环(内缩0.4, z 13.6..20.6) + 天花板(20.6..23.0, 通风栅8×6, M3过孔)
侧槽统一 z 带: z_lo=Z_TOP−0.2=8.8, z_hi=Z_TOP+组件高+0.2（端子带 8.8..20.2）
下壳 = 底板 0..2.4 + 四壁 2.4..20.6 + 铜柱（外壁到 20.6 止, 与顶盖天花板面接触）
PD 由 4.2 修正为 2.8（M3 自攻底孔 4.2 无咬丝, 属装配逻辑错误）
爆炸向量: case_top +34 / parts_F +16 / pcb 0 / case_bottom −18（爆炸态无重叠, 见 L3 测试）
```

## 3. CAD 测试体系（对标原理图 DRC / 固件单测的范式）

| 层 | 文件 | 手段 | 代表断言 |
|---|---|---|---|
| L1 单元（每网格几何健全） | test_assembly.py（纯 Python, 无 FreeCAD 依赖） | 二进制 STL struct 解析 | pcb bbox == (2.9..92.9, 2.9..77.9, 7.4..9.0) 精确黄金值; **case_top 在 SKIRT_Z0 以下零三角形**（永远拦住"带底板方盒"回归）; 天花板带/底板带/四壁带占据; 铜柱簇 ≈ ST 四点 |
| L2 接口（装配一致性, 事解析何） | 同上 | pos.csv+钻孔+槽位解析 | **钻孔 T9 ↔ ST Δ<0.2（fab⇄CAD 黄金对拍）**; 板 zmin==Z_BOARD（拦"趴底"回归）; 每个越出板边的器件盒必须落入某侧槽矩形（否则 FAIL, 拦穿壁）; 三锚点映射 |
| L3 功能（渲染资产契约） | 同上 | assembly.json+hotspots+scene.js | 清单↔STL 文件一致非空; bbox_mm ↔ 实测并集 ±0.5; 爆炸单调 + 爆炸态包围盒两两不交; hotspots z∈[Z_TOP, 20.0]; scene.js 回退 bbox 同源 |
| L4 干涉（OCC 布尔, FreeCADCmd） | test_assembly_freecad.py | STEP 布尔交集 | top∩bottom 体积 <1mm³; bottom∩PCB(实装位) <5mm³; 装配体 bbox == 黄金 ±0.3; solids ≥500 |

接入 `firmware/twin/run_tests.sh` 为第五层 CAD 套件（L1-L3 恒跑, L4 探测到 FreeCADCmd 才跑）。

## 4. 交付清单

1. `enclosure/case_geom.py`（新）: 常量+映射+锚点, 四个 make_* 全部 import, 杜绝再次分叉。
2. `make_case.py` 重写: 统一栈 + 真顶盖 + 槽带重基准 + PD 修正。
3. `make_meshes.py`/`make_flows.py`: z 改引 case_geom; 去空 parts_B; explode/bbox 更新。
4. `make_assembly.py`: 删 Y_FLIP 双分支（保留经锚点验证的映射）, 断言收紧 ±0.3。
5. 双测试文件 + run_tests.sh 第五层。
6. 重生成全部 CAD/孪生资产, 全量回归, 重建站点, 目视截图（装配+爆炸）交付用户。

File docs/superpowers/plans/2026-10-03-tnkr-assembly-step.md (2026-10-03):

# Tnkr 主模型升级实施计划

> **[已弃用 2026-10-03]** tnkr.ai 平台已放弃（展示切换 GitHub Pages）。本文仅作工程史留档，执行结论见 docs/archive/tnkr-2026-10/asset-manifest.md。

> **For agentic workers:** REQUIRED SUB-SKILL: subagent-driven-development / executing-plans。
> **前置**: spec `2026-10-03-tnkr-assembly-step-design.md` 获批 · REQUIRED: using-git-worktrees（Task 0 建隔离工作区）

**Goal:** 生成 PCB+顶盖+底壳合并装配体 STEP，升级为 Tnkr 主模型，并补全 Documentation。

**Architecture:** 三段流水线（kicad-cli 导出 → FreeCAD 合并 → 入库同步平台）；全部仓库改动在 `.worktrees/tnkr-assembly` 隔离分支完成；平台侧操作走 browser-use。

**Tech Stack:** kicad-cli 10.0 · FreeCADCmd 1.1（E:/FreeCAD/bin/）· git worktree · browser-use。

---

### Task 0: Worktree 隔离工作区

- [ ] `cd E:/FLOWIO && git check-ignore -q .worktrees || echo ".worktrees/" >> .gitignore && git add .gitignore && git commit -m "chore: ignore .worktrees"`
- [ ] `git worktree add .worktrees/tnkr-assembly -b tnkr/assembly-step`
- [ ] 基线：`"E:/FreeCAD/bin/FreeCADCmd.exe" .worktrees/tnkr-assembly/hardware/flowio-p1/enclosure/check_case.py`（或以 python 直跑）→ 通过才继续
- [ ] 记录 worktree 路径与基线结果

### Task 1: PCB STEP 导出（A 段）

**Files:**
- Create（工件）: `hardware/flowio-p1/fab/flowio-p1.step`

- [ ] 命令（worktree 内执行）:
```bash
cd E:/FLOWIO/.worktrees/tnkr-assembly
"E:/Program Files/KiCad/10.0/bin/kicad-cli" pcb export step \
  --force -o hardware/flowio-p1/fab/flowio-p1.step \
  hardware/flowio-p1/flowio-p1.kicad_pcb
```
- [ ] 验证：`ls -la hardware/flowio-p1/fab/flowio-p1.step`（预期 1-10 MB）；用 FreeCAD 一行脚本数 solid：
```bash
"E:/FreeCAD/bin/FreeCADCmd.exe" -c "import Import; s=Import.read('hardware/flowio-p1/fab/flowio-p1.step'); print(len(s.RootObjects))"
```
- [ ] 判定：solid ≥ 数十（板+元件）→ 完整版；≈1（仅板）→ 记录元件 3D 体缺失，按 spec §4.1 走降级
- [ ] 若降级重试：补 KiCad 环境变量 `KICAD8_3DMODEL_DIR`/`KICAD9_3DMODEL_DIR` 指向 `E:/Program Files/KiCad/10.0/share/kicad/3dmodels` 后重跑一次；仍缺则接受降级并记录

### Task 2: 合并装配脚本（B 段）

**Files:**
- Create: `hardware/flowio-p1/enclosure/make_assembly.py`（用 Write 工具写源码）
- Create（工件）: `hardware/flowio-p1/enclosure/flowio-p1-assembly.step`
- Create（工件，可选）: `hardware/flowio-p1/enclosure/flowio-p1-assembly.stl`

- [ ] 脚本要点（FreeCADCmd 运行）：
  1. `Import.read()` 三个 STEP：fab/flowio-p1.step、enclosure/case-bottom.step、enclosure/case-top.step
  2. 定位：读 standoffs.txt 柱高（PCB 悬浮高度）；case-bottom 原位；PCB 置于柱顶；case-top 平移至闭合位（参数与 make_case.py 的 lid 偏移一致——先读 make_case.py 提取常量）
  3. 合成 compound → 导出 STEP；顺带导出 STL（spec §4.2 默认做）
  4. 断言：装配体包围盒 X/Y ≈ 外壳外形（从 make_case.py 常量），Z = 底+高+顶盖厚，容差 ±2mm；不满足则退出码非零
- [ ] 运行 + 断言通过
- [ ] 目视：将装配体 STEP 拖入数字孪生本地页或 FreeCAD 截图留档 `enclosure/assembly_preview.png`
- [ ] Commit: `git add hardware/flowio-p1/enclosure/make_assembly.py hardware/flowio-p1/enclosure/flowio-p1-assembly.* hardware/flowio-p1/fab/flowio-p1.step && git commit -m "feat(enclosure): 合并装配体 STEP（PCB+顶+底）供 Tnkr 主模型"`

### Task 3: 合回 main + 推送

- [ ] `cd E:/FLOWIO && git merge tnkr/assembly-step --no-ff -m "merge: Tnkr 装配体主模型流水线"`
- [ ] `git push origin main`（Tnkr Files 同步的触发源）
- [ ] 清理：`git worktree remove .worktrees/tnkr-assembly && git branch -d tnkr/assembly-step`（finishing-a-development-branch 收尾）

### Task 4: Tnkr 主模型更换（browser）

- [ ] 认领用户持有的项目页标签（`browser.user.openTabs()` 匹配 tnkr.ai）；无则新开
- [ ] 打开 `https://tnkr.ai/yuefeizzzs-workspace/flowio-cn` → **Manage** → 找主 STEP/3D 模型设置项
- [ ] 改选 `flowio-p1-assembly.step`（若 Files 区未同步到新 commit，找 re-sync 入口或等待平台轮询）
- [ ] 若 Manage 无更换入口 → 执行退路：记录"主模型维持 case-top，装配体在 Files 区"，写入 asset-manifest
- [ ] 验证：Overview 出现 canvas（3D viewer），截图留档

### Task 5: Documentation 补全（browser）

- [ ] 读 Documentation 标签当前内容（Leonardo 是否已生成）
- [ ] 判定：有实质装配文档 → 仅核对；空/劣 → 进入编辑模式粘贴 `docs/tnkr/assembly-steps-en.md` 内容（10 步 + A201-A302 票号）
- [ ] 发布并验证公开可见

### Task 6: 档案回填 + 汇报

- [ ] 回填 `docs/tnkr/asset-manifest.md`（主模型状态/Documentation 状态/装配体路径）
- [ ] 回填 spec 执行注记（降级与否、solid 数、尺寸断言值）
- [ ] Commit 文档 + 向用户汇报（含项目页最终截图）

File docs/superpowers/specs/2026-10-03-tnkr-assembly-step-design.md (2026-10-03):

# Tnkr 主模型升级（合并装配体 STEP）+ Documentation 补全 — 设计规格书

> **[已弃用 2026-10-03]** tnkr.ai 平台已放弃（展示切换 GitHub Pages）。本文仅作工程史留档，执行结论见 docs/archive/tnkr-2026-10/asset-manifest.md。

> **日期**: 2026-10-03 · **状态**: 待用户审查
> **背景**: FLOWIO-CN 已上线 Tnkr（/yuefeizzzs-workspace/flowio-cn）。当前主 STEP 为单一 case-top.step（平台规则"恰好一个主模型"），零件分解观感受限；Documentation 依赖 Leonardo 异步生成，质量待核。
> **用户指令**: 认可"可选后续"①②，要求 using-superpowers + using-git-worktrees 流程。

---

## 1. 范围

| 项 | 内容 | 状态 |
|---|---|---|
| ① 合并装配体 STEP | PCB（含元件）+ case-top + case-bottom 合并为单一装配体，作为 Tnkr 主模型 | **本期核心** |
| ② Documentation 补全 | 核查 Leonardo 生成结果；不足则以 assembly-steps-en.md 内容补齐 | 本期 |
| ③ Kits 套件上架 | 平台 Kits 标签 disabled（条件未解锁），且属商业决策 | **明确出范围** |

## 2. 技术设计

### 2.1 装配体生成流水线（三段）

```
[A] kicad-cli 导出 PCB STEP（含元件 3D 体）
    "E:/Program Files/KiCad/10.0/bin/kicad-cli" pcb export step
      --force -o hardware/flowio-p1/fab/flowio-p1.step
      hardware/flowio-p1/flowio-p1.kicad_pcb

[B] FreeCADCmd 合并装配（新脚本 enclosure/make_assembly.py）
    输入: fab/flowio-p1.step + enclosure/case-top.step + enclosure/case-bottom.step
    定位: 复用 make_case.py 的板尺寸(90×75)与 standoffs.txt 的柱高参数
    输出: enclosure/flowio-p1-assembly.step（多 solid 装配体——Tnkr 拆解视图的原料）

[C] 入库 + 平台同步
    commit → push GitHub → Tnkr Files 区自动跟随仓库 → Manage 更换主 STEP
```

### 2.2 关键风险与对策

| 风险 | 对策 |
|---|---|
| KiCad 元件 3D 模型路径环境变量缺失 → 元件体缺失 | 导出后用 FreeCAD 脚本数 solid 数量；不达标降级 `--board-only`（板+外壳也有分解价值） |
| 装配体文件过大（107 元件 STEP 可达数 MB） | Tnkr 限 100MB，余量充足；GitHub 仓库增量可控 |
| Tnkr Manage 不支持更换主 STEP | 退路：删除项目重建（GitHub 导入路径 5 分钟可复现，已有 runbook）；或主模型维持 case-top、装配体放 Files 区供下载 |
| FreeCAD 合并坐标错位 | 以 standoffs.txt 实测参数为准；生成后脚本化断言（包围盒尺寸≈预期整机尺寸） |

### 2.3 Worktree 约定（using-git-worktrees）

- 目录：`.worktrees/tnkr-assembly`（项目本地隐藏目录）
- 创建前 `git check-ignore .worktrees` 验证，未忽略则先补 .gitignore + 提交
- 分支：`tnkr/assembly-step`；完成后合回 main 并 push（Tnkr Files 同步依赖 GitHub）
- 基线：工作树内跑 `enclosure/check_case.py`（既有几何自检）确认起点干净

## 3. 验收标准

1. `flowio-p1-assembly.step` 生成且含 ≥3 个 solid（顶盖/底壳/PCB 板体；含元件则数十个）
2. 装配体包围盒尺寸与预期整机外形一致（脚本断言，容差 ±2mm）
3. 合并提交推送 GitHub 后，Tnkr 项目 Files 区可见 `flowio-p1-assembly.step`
4. Tnkr 主模型更换为装配体（或按 §2.2 退路记录原因）
5. Documentation 标签有实质内容（Leonardo 生成或手动补齐，含装配步骤）
6. 主仓 main 分支仅新增：make_assembly.py + 2 个 STEP 工件 + 文档回填

## 4. 开放问题（审查时定夺）

1. PCB STEP 若元件体导出不完整：接受"板体+外壳"降级版，还是补齐 KiCad 3D 库路径后重试？（建议：先试完整版，降级版兜底，两版产物都留档）
2. 装配体是否同时导出一份合并 STL 供数字孪生复用？（建议：顺带导出，成本一行命令）

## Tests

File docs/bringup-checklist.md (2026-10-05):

# FLOWIO-CN P1.1 BRINGUP 检查表（板到货后执行 · T9 用户交付物）

> **真值源**：`hardware/flowio-p1/enclosure/devices.json` `pneumatic_devices`（器件电气/几何）·
> `docs/firmware-driver-spec.md`（驱动/互锁规格，T7 冻结）· `literature/component-param-audit.md` +
> `literature/valve-vendor-questionnaire.md`（自检兜底/三档判据）·
> spec `docs/superpowers/specs/2026-10-04-p1.1-spin-b-design.md` §7 NFR + plan T9 ·
> GPIO/位号以 `hardware/flowio-p1/tools/gen_sch.py`（原理图真值源）核对。
> **生成日期**：2026-10-05（P1.1 T9）。板：100×80 四层 / 12 路执行 / USB-C 单输入。
> **实验供电定案**：用户 **30V/10A 直流稳压电源**——参数测量用 **5.0V/10A 模式**（上限远超最坏
> 4.55A，无跌落干扰，保持占空比/启动电流/并发全开实测才准）；**CC 3A 模式**复现适配器跌落验证
> 软件互锁；两模式做完再用 3A 适配器复测。馈入方式：USB-C 电源口 J1（CC 已有 5.1k×2 下拉，
> 免诱骗，剪线 USB 线/USB-C 转 5V 香蕉线接电源输出）。
> 先决条件：JLC 收货验收（`fab/README-jlc-order.md` §5）+ **U6 XGZP 手工补焊完成**（SO-8 手焊）。

---

## A. 上电前静态检查（万用表，不接电源）

| # | 项目 | 方法 | 判据 | 记录 |
|---|---|---|---|---|
| A1 | 电源轨对地阻抗 | 电阻档测 TP2(+5V)-GND、TP1(+3V3)-GND（表笔互换各一次） | 无短路：两向读数稳定不在 0~1Ω 区（电容充电摆动后回升为正常）；记双向阻值 | ___ |
| A2 | 极性与目检 | 放大镜检查：U1 WROOM 四侧焊脚；J10-J17/J20-J23 共 12 只 XH-2P 卧贴座无歪斜浮高；J5-J9/J18/J19 七只 THT 端子；USB-C 口内无歪针 | 无连锡/偏位/异物 | ___ |
| A3 | **XGZP 焊向（U6）** | 核对丝印 pin1 标记 vs 封装 1 脚位；**N/C 脚 1/3/4/5 禁连目检**（确认仅 2/6/7/8 有焊且无桥连） | pin1 对位正确；N/C 四脚无网络无桥连（接错=器件报废，问询单红线） | ___ |
| A4 | **阀线圈电阻三档判据**（致荣 450/300 定档） | 阀插入 2P 座，电阻档跨测 J10-J17（V1-V8）、J20(S)、J22(F) 与 J21(V) | **主档**：D 阀（V1-V8/S/F）≈**10Ω→450mA 档**（4.5V/0.45A，允差 9.7~10.3Ω）；B 阀（V）≈**15Ω→300mA 档**。**异常档**：≈19Ω→240mA（行业老档）/≈50Ω→85mA（低功耗版）/≈14Ω→320mA（F 档混料）——任一出现即拍照存档暂缓该路，回填 registry | V1-V8:___ S:___ V:___ F:___ |
| A5 | 泵电机绕组 | 跨测 J23 两脚（泵模块 JST 2P 接入） | 有刷电机数 Ω 量级、记录实测值（启动电流估算依据） | ___ |

## B. 上电（30V/10A 电源 · CV 5.0V；CC 先设 0.5A 摸底，静态正常后开 CC 10A 供实测）

| # | 项目 | 方法 | 判据 | 记录 |
|---|---|---|---|---|
| B1 | 5V 轨压 | 万用表 TP2-GND | 5.00±0.25V | ___ |
| B2 | 3V3 轨压 | 万用表 TP1-GND（TPS54331 输出） | 3.3±0.1V；LED2(PWR) 亮 | ___ |
| B3 | Inrush 软启动 | 电源表头/电流探头看上电瞬间峰值 | 软启动不触发电源保护（NFR N5）；记录峰值 ___A | ___ |
| B4 | ESP32 启动日志 | J2 DATA 口 USB-C → 串口 115200（CH340N） | 见启动 banner/自检行；上电 30s 内无 boot loop | ___ |
| B5 | 静态电流 | 全阀关+泵停，电源读数 | 逻辑静态 ≤~0.2A（ESP32+外设；记录基线） | ___ |

## C. 通道逐路（12 路 GPIO 映射——`tools/gen_sch.py` 原理图真值源）

| 通道 | 位号 | GPIO | 栅阻 | MOS(AO3400A) | 续流(SS14) | XH-2P 座 | 动作 | 听声/电流 | 记录 |
|---|---|---|---|---|---|---|---|---|---|
| V1 通道阀 | F0520D | **IO4**  | R39 | Q3  | D4  | J10 | 开→保持→关 | 咔哒 + 0.50A→0.45A | ___ |
| V2 通道阀 | F0520D | **IO5**  | R40 | Q4  | D5  | J11 | 同上 | 同上 | ___ |
| V3 通道阀 | F0520D | **IO6**  | R41 | Q5  | D6  | J12 | 同上 | 同上 | ___ |
| V4 通道阀 | F0520D | **IO7**  | R42 | Q6  | D7  | J13 | 同上 | 同上 | ___ |
| V5 通道阀 | F0520D | **IO10** | R43 | Q7  | D8  | J14 | 同上 | 同上 | ___ |
| V6 通道阀 | F0520D | **IO11** | R44 | Q8  | D9  | J15 | 同上 | 同上 | ___ |
| V7 通道阀 | F0520D | **IO12** | R45 | Q9  | D10 | J16 | 同上 | 同上 | ___ |
| V8 通道阀 | F0520D | **IO21** | R46 | Q10 | D11 | J17 | 同上 | 同上 | ___ |
| S 充气主阀 | F0520D | **IO15** | R55 | Q13 | D12 | J20 | 同上 | 咔哒 + 0.50A→0.45A | ___ |
| V 真空主阀 | F0520B | **IO16** | R56 | Q14 | D13 | J21 | 同上 | 咔哒 + 0.33A→0.30A | ___ |
| F 排气主阀 | F0520D | **IO17** | R57 | Q15 | D14 | J22 | 同上 | 咔哒 + 0.50A→0.45A | ___ |
| PUMP 泵 | ZR370-03PM | **IO18** | R58 | Q16 | D15 | J23（JST 2P 泵模块） | 起→停（占空比 ≤95%） | 泵转声 + <0.5A 负载 | ___ |

- 方法：逐路单开（PWM 驱动：吸入 100%≤100ms → 全开保持 90%=230/255）听阀咔哒/看电流表两段步进（瞬态→保持回落）后关闭；
- 判据：12/12 路动作、无一路虚焊/座不良；电流与上表档位一致（A4 结论互证）；
- 注：传感 I2C **SDA=IO8 / SCL=IO9**（R8/R9 上拉 4.7k）；泵驱动 MOS 为 **Q16**（gen_sch/make_flows 真值；
  devices.json 泵条目文中"Q12"为 T1 期旧号，以原理图为准——Q12 实为 CH340 自动复位三极管）。

## D. 气动实测（整机接管后；气路拓扑见 `docs/pneumatic-diagram.md`）

| # | 项目 | 方法 | 判据 | 记录 |
|---|---|---|---|---|
| D1 | **保压泄漏**（NFR N2） | 全阀关（NC 断电自闭），CH 口外接 N2/打气筒充 ~30kPa，监视 30min（XGZP 读数或外接表；50mL 等效容积口径） | **30min 压降 ≤5kPa**；超标则夹管钳分段隔离定位（歧管/通道管/主阀/快插） | ___ |
| D2 | **最坏 9 阀保持实测** | V1-V8+S 全开保持(90%)+泵 95%，5.0V/10A 模式读母线电流 | 实测 ≈**4.53A**（孪生 4.525A/registry 4.55A 同式）——**>3A 属预期受限模式**：固件须报 `OVERLOAD 0x01` 并给错峰/节能建议；错峰对策实测（9 阀节能 55%+泵 95%）≈2.95A ≤3A | 实测 ___A / 告警 有☐无☐ |
| D3 | **35kPa 背压最小保持占空比** | 单通道充至 35kPa，保持占空比自 **55%** 起扫描（5% 步进），找阀不脱开的最小值 | 得到"最小可靠保持占空比"；55% 不足则升 65~70% 重扫；结果回填 registry `drive_policy`（55% 为起点值） | 最小占空比 ___% |
| D4 | **泵死头压力** | 堵泵出口测充压上限/堵入口测抽气极限（XGZP 或机械表，注意超 ±45kPa 阀额定段隔离） | 实测 ≥**+120kPa** / ≤**-60kPa**（型号标称验证，devices.json `pump.pressure_kpa`） | +___kPa / −___kPa |
| D5 | **过压停泵互锁** | 诊断模式强制充气至 M>+35kPa；再抽气至 M<−40kPa | M>**+35kPa** → 泵占空比强制 0 + 告警 `OVERPRESSURE 0x02`；M<**−40kPa** → `VACUUM_CLAMP 0x04`（真空钳位，由 −50 收紧至 −40）；工作带 ±35kPa 闭环生效 | 两路触发 有☐无☐ |
| D6 | **D 阀负压 −40kPa 验证** | V 路抽气至 −40kPa 附近，观察通道阀（F0520D）保持关断/无异响/无内漏 | D 阀在 −40kPa 下可靠关断（吸模式前提；**待商家确认项 H1**，不通则启用兜底：V 路改双 B 阀串联 BOM+1） | ___ |
| D7 | **VF 静止密封方向确认** | D1 保压工况下验证 V:F 口侧：F 壁孔管口/消音棉位涂皂液，压降曲线与不接 VF 短管对照 | F 口侧无泡、压降无异速段 —— datasheet "正压接N2"设计向下 VF 装配朝向相反（满压在 N1/M 侧，大气口恒 0），静止密封方向未验证（`connections.json` conventions.n1_n2_semantics）；异常则对照问询单 0520D §8 答复评估换向 | ___ |

## E. 传感（XGZP6897D 非-C · `docs/firmware-driver-spec.md` §1）

| # | 项目 | 方法 | 判据 | 记录 |
|---|---|---|---|---|
| E1 | **0x6D 读通** | I2C 总线扫描（SDA=IO8/SCL=IO9，≤400kHz） | 见 **0x6D** 应答；读 0x01 PartID 一次在位校验；NACK/PartID 错→`PN_SW_ERROR` 闭环禁启 | ___ |
| E2 | 寄存器流程 | 写 0x30←0x0A（组合采集）→ 轮询 0x02 等 Sco 清零（响应 2.5ms）→ 读 0x06/07/08 压力 24bit + 0x09/0A 温度 | 换算 **P=ADC/k，k=32（Span200）**；T=/256；吹气/吸球对拍读数方向与幅值合理（禁用 -C 的 0x04 连读流程） | P=___ T=___ |
| E3 | **零点置零策略** | 上电自检（N10）：全阀关、气路常压下取均值记偏移；每次开机自动执行 | 零偏 ≤±2kPa（±2%Span 内）；记录开机零偏用于回流零漂跟踪 | 零偏 ___kPa |

## F. CC 3A 模式复现适配器跌落（NFR N5）

| # | 项目 | 方法 | 判据 | 记录 |
|---|---|---|---|---|
| F1 | 限流跌落复现 | 电源切 **CC 3A**，重放 D2 最坏 9 阀+泵 | 电压被拉低→固件 `OVERLOAD` + 受限模式（错峰：并发全开保持 ≤4 通道，或降节能保持）；**软启动互锁验证：0 通道开 → 泵强制 0**（interlock） | ___ |
| F2 | 跌落不脱阀 | CC 模式人为压轨 5V→4.5V，阀保持态听声/电流 | 4.5V 下阀不脱开（保持占空比依据）；瞬断 <100ms 恢复后状态一致 | ___ |
| F3 | 3A 适配器复测 | 换 USB-C 5V/3A 适配器重复 D2/F1 关键项 | 记录真实跌落/恢复曲线；据此**定适配器档（3A/4A/5A）**回填 registry 功率预算 | 结论：___ |

## G. NFR 抽测（spec §7）

| # | NFR | 方法 | 判据 | 记录 |
|---|-----|---|---|---|
| G1 | N1 热 | 9 阀保持+泵连续 10min，热电偶/红外测最高阀体与壳内温升 | **阀体 ≤60°C**（安全线 67°C）；环境+自热组合 ≤45°C 上限口径 | ___°C |
| G2 | N6 EMC/EMI | I2C 连续 10min 误码统计，泵转/停两组对比；BLE 保持连接 | **误码=0**；BLE/WiFi 不掉线；传感读数无毛刺 | ___ |
| G3 | N7 噪声 | 声级计 @30cm，泵满占空比（硅胶支架+海绵垫装机态） | **≤60dB**（泵规格上限）；拉抽测管路不脱接 | ___dB |
| G4 | N9 跌落 | 装配态 50cm 自由落体（六面），复测上电+六动作 | 功能正常、管路/端子无脱接 | ___ |
| G5 | N4 老化（可选） | 72h 间歇老化台架（阀 10s/5s 节奏抽样） | 无异常（样机验收=出厂自检+72h 间歇老化） | ___ |

## H. 待关闭项清单（BRINGUP 期间收敛）

| # | 项 | 现状 | 关闭动作 |
|---|----|---|---|
| H1 | **F0520D 负压能力商家确认** | 通道阀吸模式受负压；设计按 −40kPa 待验 | 商家答复 或 D6 实测定案；不通则兜底 V 路双 B 阀串联（BOM+1） |
| H2 | **3.7V 样品参数自采** | 规格书无 3.7V 列（P2 电池泵模块条件路线） | 3 只样品 30V/10A 电源设 3.7V：线圈电阻/最低动作电压/压比/电流→回填 registry §1/§2→P2 选型生效 |
| H3 | **端子高度遗留项** | **已消解确认**：终裁 14.0mm（JLC 属性 14.07+型号尾缀 14-00A 双源一致；壳链 26.07 维持） | 到货卡尺抽验 14.0±0.1 即闭环存档 |
| H4 | 有孔变体孔位 | D 阀 C 架翻边孔位/VV ⌀2.0×2 孔距待商家 | 答复入支架图纸（采购单 §5 问询项 1/3） |
| H5 | 2P 白壳连接器型号 | 问询单 D-6 待答 | 与 BOM C7429671 卧贴座对拍；不同款则换同款插座入 BOM |

<!-- BEGIN GENERATED:bringup-piping (tools/gen_bringup_piping.py; 禁手改, 重跑再生) -->
## I. 模块间连接与管路下料（机器生成 · connections.json 真值）

> **生成**：`python tools/gen_bringup_piping.py` @ 2026-10-05 · 生成于 device-modeling DX 收官 ·
> 真值源 `hardware/flowio-p1/enclosure/connections.json`（29 气 + 14 电 + 15 机 = 58 边，只读）·
> 折线几何 = `flowio/twin/connections_render.py` 渲染单源（与 `webapp/connections_scene.json` 同源）·
> WARN 清单 = `flowio.twin.connections.validate()` 现值（`python -m flowio connections --check`：0 FAIL / 4 WARN）。
> **下料口径**（scene meta bend_note）：tube.bend=2 为采购下料名义值；渲染折线按最小几何弯折
> （2~4 点，壁孔过越/障碍让位）—— **折线段长和 ≤ 下料长 len_mm，差值即布管余量；采购/下料以
> len_mm（真值列）为准**，折线段长和仅为装配态最小路径参考。承插 11 边 + 大气 2 边无下料
> （器件嘴直插歧管承口 / 开放大气）。本节与 A~H 章无数字口径冲突（生成脚本已断言 §C J 座映射
> 一致性）；bend 列为下料名义弯数（真值），非渲染折线点数。模块间恰 3 边的缺失后果矩阵与装配
> 顺序见 [`docs/module-interface-spec.md`](module-interface-spec.md) §4/§5，待实测项关闭通道见其 §6。

### I.1 管路下料表（16 条 tube 边 = 气路全量有几何边，序 = connections.json 真值序）

| # | 域 | 管边 from→to | 规格 | 下料真值 len_mm | 折线段长和 | 余量 | 弯 | 状态 |
|---|----|---|---|---|---|---|----|---|
| 1 | 主阀干管 | `Main.S_wall` → `VS.N2` | ID5→3×OD7 变径 | 200 | 23.3 | 176.7 | 2 | — |
| 2 | 主阀干管 | `Main.V_wall` → `VV.N2` | ID5→3×OD7 变径 | 200 | 17.8 | 182.2 | 2 | **inferred：待实测** |
| 3 | 主阀干管 | `VF.N2` → `Main.F_wall` | ID3×OD7 | 200 | 23.3 | 176.7 | 2 | — |
| 4 | 通道管 | `V1.N2` → `Main.CH1` | ID3×OD7 | 175 | 17.0 | 157.9 | 2 | — |
| 5 | 通道管 | `V2.N2` → `Main.CH2` | ID3×OD7 | 175 | 26.5 | 148.4 | 2 | — |
| 6 | 通道管 | `V3.N2` → `Main.CH3` | ID3×OD7 | 175 | 36.0 | 138.9 | 2 | — |
| 7 | 通道管 | `V4.N2` → `Main.CH4` | ID3×OD7 | 175 | 45.5 | 129.4 | 2 | — |
| 8 | 通道管 | `V5.N2` → `Main.CH5` | ID3×OD7 | 175 | 80.0 | 95.0 | 2 | — |
| 9 | 通道管 | `V6.N2` → `Main.CH6` | ID3×OD7 | 175 | 70.5 | 104.5 | 2 | — |
| 10 | 通道管 | `V7.N2` → `Main.CH7` | ID3×OD7 | 175 | 61.0 | 114.0 | 2 | — |
| 11 | 通道管 | `V8.N2` → `Main.CH8` | ID3×OD7 | 175 | 51.5 | 123.5 | 2 | — |
| 12 | 泵模块跳管 | `P1.CHG` → `PMod.S_panel` | ID5×OD7 | 150 | 52.2 | 97.8 | 2 | **fit_pending：到货试装 4/5 取一，ID4 备料** |
| 13 | 泵模块跳管 | `P1.SUCK` → `PMod.V_panel` | ID5×OD7 | 150 | 43.5 | 106.5 | 2 | **fit_pending：到货试装 4/5 取一，ID4 备料** |
| 14 | 模块间干管 | `PMod.S_panel` → `Main.S_wall` | ID5×OD7 | 350 | 99.9 | 250.1 | 2 | — |
| 15 | 模块间干管 | `PMod.V_panel` → `Main.V_wall` | ID5×OD7 | 350 | 101.4 | 248.6 | 2 | — |
| 16 | 测压支路 | `Main.M` → `S1.P1` | ID3×OD7 | 500 | 122.3 | 377.7 | 2 | — |

### I.2 WARN 边清单（恰 4 条 = 2 fit_pending + 2 inferred，与 spec §6 待实测清单对齐；内容列 = validate() 原文）

| WARN 类 | 边 | validate() 原文 | BRINGUP 关闭动作 |
|---|----|---|---|
| inferred | `Main.V_wall`→`VV.N2` | WARN[inferred] 端点 VV.N2 (device VV.pneumatic_ports, VV.N2) — 边 Main.V_wall→VV.N2; D1 占位, BRINGUP 实测校正 | 卡尺实测校正（devices.json geom3d VV.N2 note；spec §6 行 1） |
| inferred | `VV.mount_hole`→`Main.valve_bracket` | WARN[inferred] 端点 VV.mount_hole (device VV.mech_mounts, VV.mount_hole) — 边 VV.mount_hole→Main.valve_bracket; D1 占位, BRINGUP 实测校正 | 商家答复（procurement H4 / 问询 1/3）→ 支架图纸（spec §6 行 2） |
| fit_pending | `P1.CHG`→`PMod.S_panel` | WARN[fit_pending] 气边 P1.CHG→PMod.S_panel: tube.id 5 > 端点 P1.CHG 嘴径 4.2 (registry §6 'ID5×OD7 定案+到货试装 4/5 取一' (泵嘴 ⌀4.2, id>嘴径 到货定档)) — registry §6 到货试装定档 | **到货试装 4/5 取一，ID4 备料**；勿强行扩口，定档回填 registry §6 / connections.json |
| fit_pending | `P1.SUCK`→`PMod.V_panel` | WARN[fit_pending] 气边 P1.SUCK→PMod.V_panel: tube.id 5 > 端点 P1.SUCK 嘴径 4.2 (registry §6 同上 (泵嘴 ⌀4.2)) — registry §6 到货试装定档 | **到货试装 4/5 取一，ID4 备料**；勿强行扩口，定档回填 registry §6 / connections.json |

### I.3 电气线束（connections.json electrical_edges 14 边，桩深口径机器提取）

- 阀引线 lead_2p ×11：各 **60mm** 2P 白壳→XH 座（§C 通道表 J 座映射一致性已由生成脚本断言：
  V1-V8→J10-J17 / VS→J20 / VV→J21 / VF→J22）；
- 泵电机电缆 cable_2p ×1：**150mm**（Main.J23 ↔ PMod.cable_2p，XH2.54-2P，spec §4 模块间 3 边之一）；
- 模块内电机引线 wire ×2：len_mm=null **待实测**（D2-A 视觉桩深度，泵端焊片正/负极以图纸标注为准）。
<!-- END GENERATED:bringup-piping -->

**收尾**：全部勾完后——D3/F3/H1/H2 结论回填 `docs/component-registry.md` + `devices.json`
（先改表再改库，commit 关联），`firmware-driver-spec.md` §2/§3 数值随 registry 联动更新并重跑
`firmware/twin/run_tests.sh` 全链。

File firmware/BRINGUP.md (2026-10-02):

# BRINGUP.md — P1 回板动线清单（固件侧视角）

> 范围：`docs/superpowers/specs/2026-10-02-p1-board-twin-design.md` §8.5（回板验证清单）
> + §10.2（电气校准 6 项）+ §10.1（泵三实验）合流。每项跑完打勾并记录产物。
> 硬件假设：ESP32-S3-N16R8（YD-ESP32-S3），阀 GPIO 4/5/6/7/10/11/12、泵 21、I2C SDA=8/SCL=9、WS2812=48。
> 串口 115200（CH340K 丝印 COM 口）；上电 30s 内按住 BOOT（GPIO0）≥1s 可禁用呼吸演示循环。

## 1. CH340K 烧录与自动复位

> 对应工单: A201（首电三测）, A202（CH340 烧录/自动复位）

- [ ] `powershell build_n16r8.ps1` 全量构建通过（16MB Flash / 8MB PSRAM / 240MHz）
- [ ] `powershell flash_com3.ps1`（esptool 直烧 COM3 @460800，`--before default_reset` 自动进下载模式）完成三镜像：bootloader@0x0 / partition-table@0x8000 / flowio_p0.bin@0x10000
- [ ] 烧毕 `hard_reset` 自动重启，串口见到 `[BOOT] hal init...` → `FlowIO-compatible P0 ready. state=0x0000`
- [ ] **产物**：flash_output.log 片段（含 hash 校验行）贴回本节

## 2. 74HCT245 / MOS 触发

> 对应工单: A203（74HCT245 电平迁移）, A204（MOS 触发栅极/Vds 波形）

- [ ] 串口发 `O 1` / `C 1`，示波器/万用表确认 74HCT245 输出侧随 GPIO4 电平翻转（3.3V→5V 电平迁移正确）
- [ ] 确认 AO3400 栅极波形干净（无振荡），导通时 Vds 接近手册值（见 §7 RDS 项）
- [ ] **产物**：波形照片 + 测得 Vds 数值记录

## 3. TCA9548A 五通道实测扫描

> 对应工单: A206（TCA 五通道扫描）

- [ ] 串口发 `W`（bring-up 诊断：I2C 全总线扫描），期望每通道报 0x58（XGZP）而空通道仅 0x70（TCA 自身）
- [ ] `P` 命令双传感器读数非错误码（实测 kPa 或 ABSENT 明确区分）
- [ ] **产物**：`W` + `P` 的串口输出贴回

## 4. WS2812 点亮

> 对应工单: A205（WS2812 状态灯）

- [ ] 上电后 `[HAL] ws2812@GPIO48 ready`，IDLE=呼吸蓝
- [ ] 发 `I 1 255` → 转绿（RUNNING）；`S 1` → 回蓝；注：ERR=红闪 / HOLD=青 映射表见固件常量
- [ ] **产物**：状态灯随命令切换的短录像/描述

## 5. 8 阀全功能

> 对应工单: A207（8 阀全功能：听声+电流）

- [ ] 逐路 `O <mask>` 掩码扫描（1/2/4/8/10/INLET/VENT——阀 7 只 + 泵共 8 执行器），听阀咔哒、看状态字位
- [ ] `I 31 255` 全充 → `V 31 255` 抽 → `R 31` 释放 → `S 31` 保压，`T` 查状态字全程正确
- [ ] **产物**：`T` 输出序列记录

## 6. I2C 速率决策

> 对应工单: A208（I2C tr 实测：100/400kHz 裁决）

- [ ] 首选 100kHz（当前固件默认，`hal_esp32.c` scl_speed_hz=100000）实测 tr/波形干净即保持
- [ ] 需提速时 400kHz 须示波器量 tr（上拉强度/线长决定），不达标不切换
- [ ] **产物**：示波器 SCL/SDA 截图 + 结论（100k 或 400k）

## 7. 电气校准 6 项（spec §10.2 表 → 改 `twin/board_model.py` BOARD_PARAMS → UI 黄徽章转绿）

> 对应工单: A211–A215（电气校准①–⑥）· A301–A303（CAL 孪生对拍：电流/效率/温升）

| # | 参数 | 现值来源 | 回板校准法 | 完成 |
|---|---|---|---|---|
| 1 | 阀线圈 R=14Ω / L=25mH | 行业典型值（假设） | 万用表测 R + LCR 表测 L，改 BOARD_PARAMS | - [ ] |
| 2 | AO3400 RDS=40mΩ@3.3V | 数据手册曲线 | 示波器 Vds 波形反推 | - [ ] |
| 3 | buck ESR=45mΩ / Cout | 仿真标称 | 示波器纹波实测反推 ESR | - [ ] |
| 4 | 负载调整率 / 效率 87.6% | 仿真套件输出 | 回板 4 线法效率实测 | - [ ] |
| 5 | θja（MOS 350 / buck 130 / ESP32 35 ℃/W） | 封装热阻手册值 | 红外/热电偶对照修正 | - [ ] |
| 6 | ESP32 逻辑电流 0.43A | 峰值估算 | 电流钳实测（含 WiFi 活动系数） | - [ ] |

- [ ] 六项实测后更新 BOARD_PARAMS + 同步金样单测（`test_board_model.py`），孪生遥测面板"模型参数：理论值（未本机标定）"黄徽章转绿
- [ ] **产物**：实测值对照表（本表扩展列）+ board_model.py diff

## 8. BLE 三步（契约：`twin/BLE.md`）

> 对应工单: A209（BLE 三步）, A210（gui 真机模式 Web Bluetooth）

- [ ] nRF Connect（手机/App）扫描到广播名 `FLOWIO-P1-<序列后缀>`（just-works 配对）
- [ ] 向 Command 服务 cmd 特征（write，UUID 后缀 0002）写 0xA5 帧（≤20B）→ resp 特征（notify，0003）收到应答帧
- [ ] 订阅 Telemetry state 特征（notify，0005，写 notify_en=1）→ 10Hz 20B state 帧（state u16 + 5×pressure i16LE(kPa×10) + tick u16）
- [ ] **产物**：nRF Connect 截图（四服务树 + notify 流）

## 9. 泵三实验（气动参数标定，`twin/calibrate_pump.py`）

> 对应工单: A216–A219（泵三实验 + 闭环充气）· A220–A224（§9+ 整机五项：装配/气密/长跑/轮巡/纹波）· A304–A306（CAL 孪生对拍）

- [ ] 实验A 充气死点：堵死充气口（或全密封），`I 31 255` 30s 每秒记录 sensors[0] → CSV
- [ ] 实验B 真空死点：堵死气路，`V 31 255` 30s 每秒记录 → CSV
- [ ] 实验C 升压曲线：接实际执行器容积，`I 1 255` 从 0 到死点每 0.5s 记录 → CSV
- [ ] `python calibrate_pump.py <csv>` 拟合 → 按输出改 `twin_api.c` PUMP_* 常数
- [ ] **产物**：三份 CSV + 拟合输出 + twin_api.c diff

## 完成标准

全部勾选后：本文件无空 checkbox；电气黄徽章转绿（§7）；气动常数换本机实测值（§9）。

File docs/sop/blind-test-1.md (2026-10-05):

# SOP Skill 盲测记录 #1（2026-10-05，plan A4）

- 方法：fresh 子代理仅加载用户级 flowio-sop（SKILL.md + rebuild-matrix.json），禁止读仓库代码与使用背景知识。
- 任务：①改 PLACE 重走链推演 ②淘宝电磁阀新增数据面推演。
- 结果：**功能通过**——两任务推演链、解释器选择、同步面、三条环境陷阱（freerouting max_passes/DSN 电源网、SWIG 毒化、Mimosa+worktree add -A）全部答对。
- 卡点：11 条——6 条真实（cwd 基准不统一/L5 两档语义/负压域约束未内联/DSN-SES 与基线路径/连带判据/淘宝 ingest 入口）已修补入 SKILL.md+matrix（commit 6a01897）并重新部署；5 条合理留白（参数明细/字段 schema 等本就属 repo 文件职责，skill 指向文件即可）不改。
- 结论：期 A 验收达成——新会话凭 skill 可完成流程推演无阻塞卡点。

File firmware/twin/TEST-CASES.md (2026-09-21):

# FlowIO-CN P0 数字孪生 · 测试用例文档 v1.1

> 状态：**待用户审查**（2026-09-21，v1.1 随孪生物理模型升级更新）
> 对应被测对象：`gui.html`（唯一前端）+ `server.py` + `pn_twin.dll`（一阶气动物理）
> 总计 **106 项断言**：接口 41 · 单元 28 · 功能 37，当前全绿

## 0. 如何运行

```bash
cd firmware/twin
bash run_tests.sh          # 一键：自起 8017 隔离实例 → 冒烟+接口+单元+功能 → 自动清理
```

- **测试隔离**：run_tests.sh 在 8017 端口自起独立实例（含残留实例清场 + 物理签名验证，防 Windows 双绑定幽灵），与浏览器正在使用的 8000 互不干扰
- 单独运行：`bash test_api.sh`（自起实例）· `node test_gui.js` / `node test_e2e.js`（需 8017 就绪或设 `TWIN_URL`）
- 环境变量：`TWIN_PYTHON` · `TWIN_URL` · `TWIN_CHROME`；单元/功能另需 playwright-core（`NODE_PATH` 指向其 node_modules）

## 0.5 孪生物理模型（本轮被测对象）

v1.1 起物理按一阶气动规律实现（twin_api.c，参数为 P0 标定占位）：

| 规律 | 模型 | 占位参数 |
|---|---|---|
| 泵充压 | dp/dt = K·(duty/255)·(1 − p/Pmax)，渐近死点 | K=30kPa/s，Pmax=65kPa（规格 50–70 取中） |
| 泵抽真空 | 对称模型，渐近极限真空 | Pmin=−45kPa |
| 被动排气 | 指数衰减 p∝e^(−t/τ)（压差驱动，负压自然回充） | τ=1.6s |
| 密封微漏 | 漏率 ∝ 压差 | 1%/s |
| 传感器 | XGZP6897D 量程 ±100kPa，注入与演化均按量程饱和 | ±100kPa |

**⚠ 重要发现（固件设计缺陷，待用户决策）**：超压保护阈值 120kPa 高于传感器量程上限 100kPa——真机与孪生上该保护**永远无法触发**（盲区）。孪生如实建模（注入 125 只会饱和显示 100、不触发保护）。建议将阈值降到量程内（如 90kPa），等你拍板后一并改固件与孪生。

## 1. 接口测试用例（41 项 · test_api.sh）

前置：隔离实例已启动；物理测量类用例每项先 `POST /api/reset` 归零（`S 31` 只关阀不清压）。

### A. 协议契约（API-01~09）

| ID | 用例 | 预期 |
|----|---|---|
| API-01~06 | GET /api/state 字段完整性 | 含 state / valves / pump / sensors / cl / err |
| API-07 | valves 数组结构 | 长度 7 |
| API-08 | cl 枚举 | ∈ {IDLE, RUNNING, DONE, TIMEOUT, ERR} |
| API-09 | POST /api/cmd 回包 | `{ok: true}` |

### B. 充气 `I 7 255`（API-10~16）

| ID | 用例 | 预期 |
|----|---|---|
| API-10 | 状态字 | 0x02A7 |
| API-11 | 端口阀 duty | 1-3 >0；4/5 =0 |
| API-12 | 方向阀 duty | 进气 >0；排气 =0 |
| API-13 | 泵 duty | =255 |
| API-14 | 升压 | 0.4s >5 kPa（≈30kPa/s@duty255） |
| API-15 | 持续充气 | 单调上升 >+15 kPa |
| API-16 | 阀保持节能 | 500ms 后 duty ≤170 |

### C. 保压 `S 7`（API-17~19）

| ID | 用例 | 预期 |
|----|---|---|
| API-17 | 状态字 | 0x0200 |
| API-18 | 全停 | 7 阀 0、泵停 |
| API-19 | 比例微漏 | 0.6s 缓降 <0.5 kPa |

### D. 释放 `R 7`（API-20~22）

| ID | 用例 | 预期 |
|----|---|---|
| API-20 | 状态字 | 0x0247 |
| API-21 | 阀型 | 排气 >0、进气 =0、泵停 |
| API-22 | **指数衰减规律** | 1s 比值 p2/p1 ∈ 0.35~0.72（理论 e^(−1/1.6)≈0.53，与起点无关） |

### E. 抽气 `V 7 255`（API-23~24）

| ID | 用例 | 预期 |
|----|---|---|
| API-23 | 状态字 | 0x02C7 |
| API-24 | 泵 duty | =255 |

### F. 压力闭环 `G 7 40 0`（API-25~28）

| ID | 用例 | 预期 |
|----|---|---|
| API-25 | 启动 | cl=RUNNING |
| API-26 | 达标 | cl=DONE |
| API-27 | 精度 | 40±3 kPa |
| API-28 | 完成动作 | 自动关阀、泵停 |

### G. 仿真注入 `/api/sim`（API-29~32）

| ID | 用例 | 预期 |
|----|---|---|
| API-29 | 注入 S1=66 | `{ok:true}` |
| API-30 | 读数 | 66.0 |
| API-31 | 复位 | 0.0 |
| API-32 | 非法输入 | `{ok:false}` |

### H. 传感器量程饱和与保护盲区（API-33~36）

| ID | 用例 | 预期 |
|----|---|---|
| API-33 | 注入 125 | 按量程饱和 ∈99~101（真实传感器行为） |
| API-34 | 注入 −150 | 饱和 ∈−101~−99 |
| API-35 | 盲区验证 | 饱和不触发超压 err=0（阈值 120>量程 100，§0.5 发现） |
| API-36 | POST /api/reset | `{ok:true}`（虚拟断电） |

### I. 一阶气动物理模型（API-37~41）

| ID | 用例 | 预期 |
|----|---|---|
| API-37 | duty 缩放 | 零表压起 1s：duty255 比 duty100 升压 >1.8 倍 |
| API-38 | 泵压死点 | 连续充 8s 渐近 55~70kPa（不出现 130 假上限） |
| API-39 | 真空 | 抽气 1s 产生负压 <−15kPa |
| API-40 | 真空极限 | 连续抽 8s 渐近 −50~−35kPa |
| API-41 | 负压密封 | 缓慢回充（朝 0 方向） |

## 2. 单元测试用例（28 项 · test_gui.js）

方法：真实页面上下文中对函数级单元做输入→输出断言。

| 组 | ID | 覆盖 |
|----|----|---|
| buildFlowPaths 气流路径 | U-01~09 | 充气 5 段/干管/上行至气球/零长段防护/闭口无分支/抽气全程/无口干路/释放干路+分支/空场景 |
| balloonScale 气球缩放 | U-10~13 | 0→0.45 静息；65（泵死点）→1.0；负压 −45→0.30 吸瘪、超钳 1.0；33→≈0.729 |
| togglePort 掩码 | U-14~17 | 初始 7/取消/重选/清空兜底 |
| updRow+行操作 | U-18~21 | 写入/非法输入护栏/加减行/复位 |
| schedPlay 计时器编排 | U-22~26 | 5 计时器/偏移 0-3000-5000-7000/完成+400ms/禁用/停止清空 |
| 请求体 | U-27~28 | cmd 原文透传 / sim body |

## 3. 功能测试用例（37 项 · test_e2e.js）

前置：8017 隔离实例；真实 Chromium；开头 `POST /api/reset` 从零开始。

| 组 | ID | 覆盖 |
|----|----|---|
| 页面加载 | E-01~07 | 5 卡片/端口4-5 已启用/默认 4 行/日志/ECharts canvas/SVG 就位/0 JS 错误 |
| 充气 | E-08~13 | 活塞导通/叶轮/全路径气流 5 条/气球长大/压力上升/卡片压力跟随 |
| 保压 | E-14~17 | 气流消失/泵停/气球密封定格/卡片压力保持 |
| 释放/抽气 | E-18~22 | 释放 4 条绿色/压力降/抽气 3 条全程紫色/泵运转/停转验证 |
| 卡片与序列 | E-23~27 | 单口动作/单口掩码/按时序执行+高亮/真实驱动气路/停止复位 |
| 参数与闭环 | E-28~31 | PWM 滑块 150→泵 duty=150/◎闭环启动/DONE/60±4kPa |
| 注入 | E-32 | 注入按钮 S1=42.0 |
| 传感器饱和 | E-33~34 | 注入 125→压力表≈100/不触发盲区横幅 |
| 刷新 | E-35~37 | 布局恢复/轮询正常/全程 0 JS 错误 |

## 4. 未覆盖项与已知限制（审查重点）

| 项 | 说明 | 建议 |
|----|---|---|
| **超压保护盲区**（§0.5） | 阈值 120>量程 100，保护永不触发；UI 横幅/虚拟断电保留待真有错误源时使用 | **待你决策**：阈值降 90？|
| 物理标定参数 | Pmax 65/真空 −45/τ1.6/K30 为占位值 | 到货实测后修正（twin_api.c 宏） |
| `F 自检`输出 | printf 在服务端控制台 | 需 server.py 输出回传通道 |
| S1 演化 | 孪生只演化 S0；S1 为注入探头（页面已注明） | 模型边界 |
| 3D 页面 | 已归档不测 | — |

## 5. 审查指引

1. **§0.5 物理模型与参数**——规律对不对？占位值合不合理？**超压阈值怎么定？**
2. §1.I 物理用例的判定窗口（比值区间、渐近区间）是否可接受？
3. §3 交互预期是否符合你的使用习惯？

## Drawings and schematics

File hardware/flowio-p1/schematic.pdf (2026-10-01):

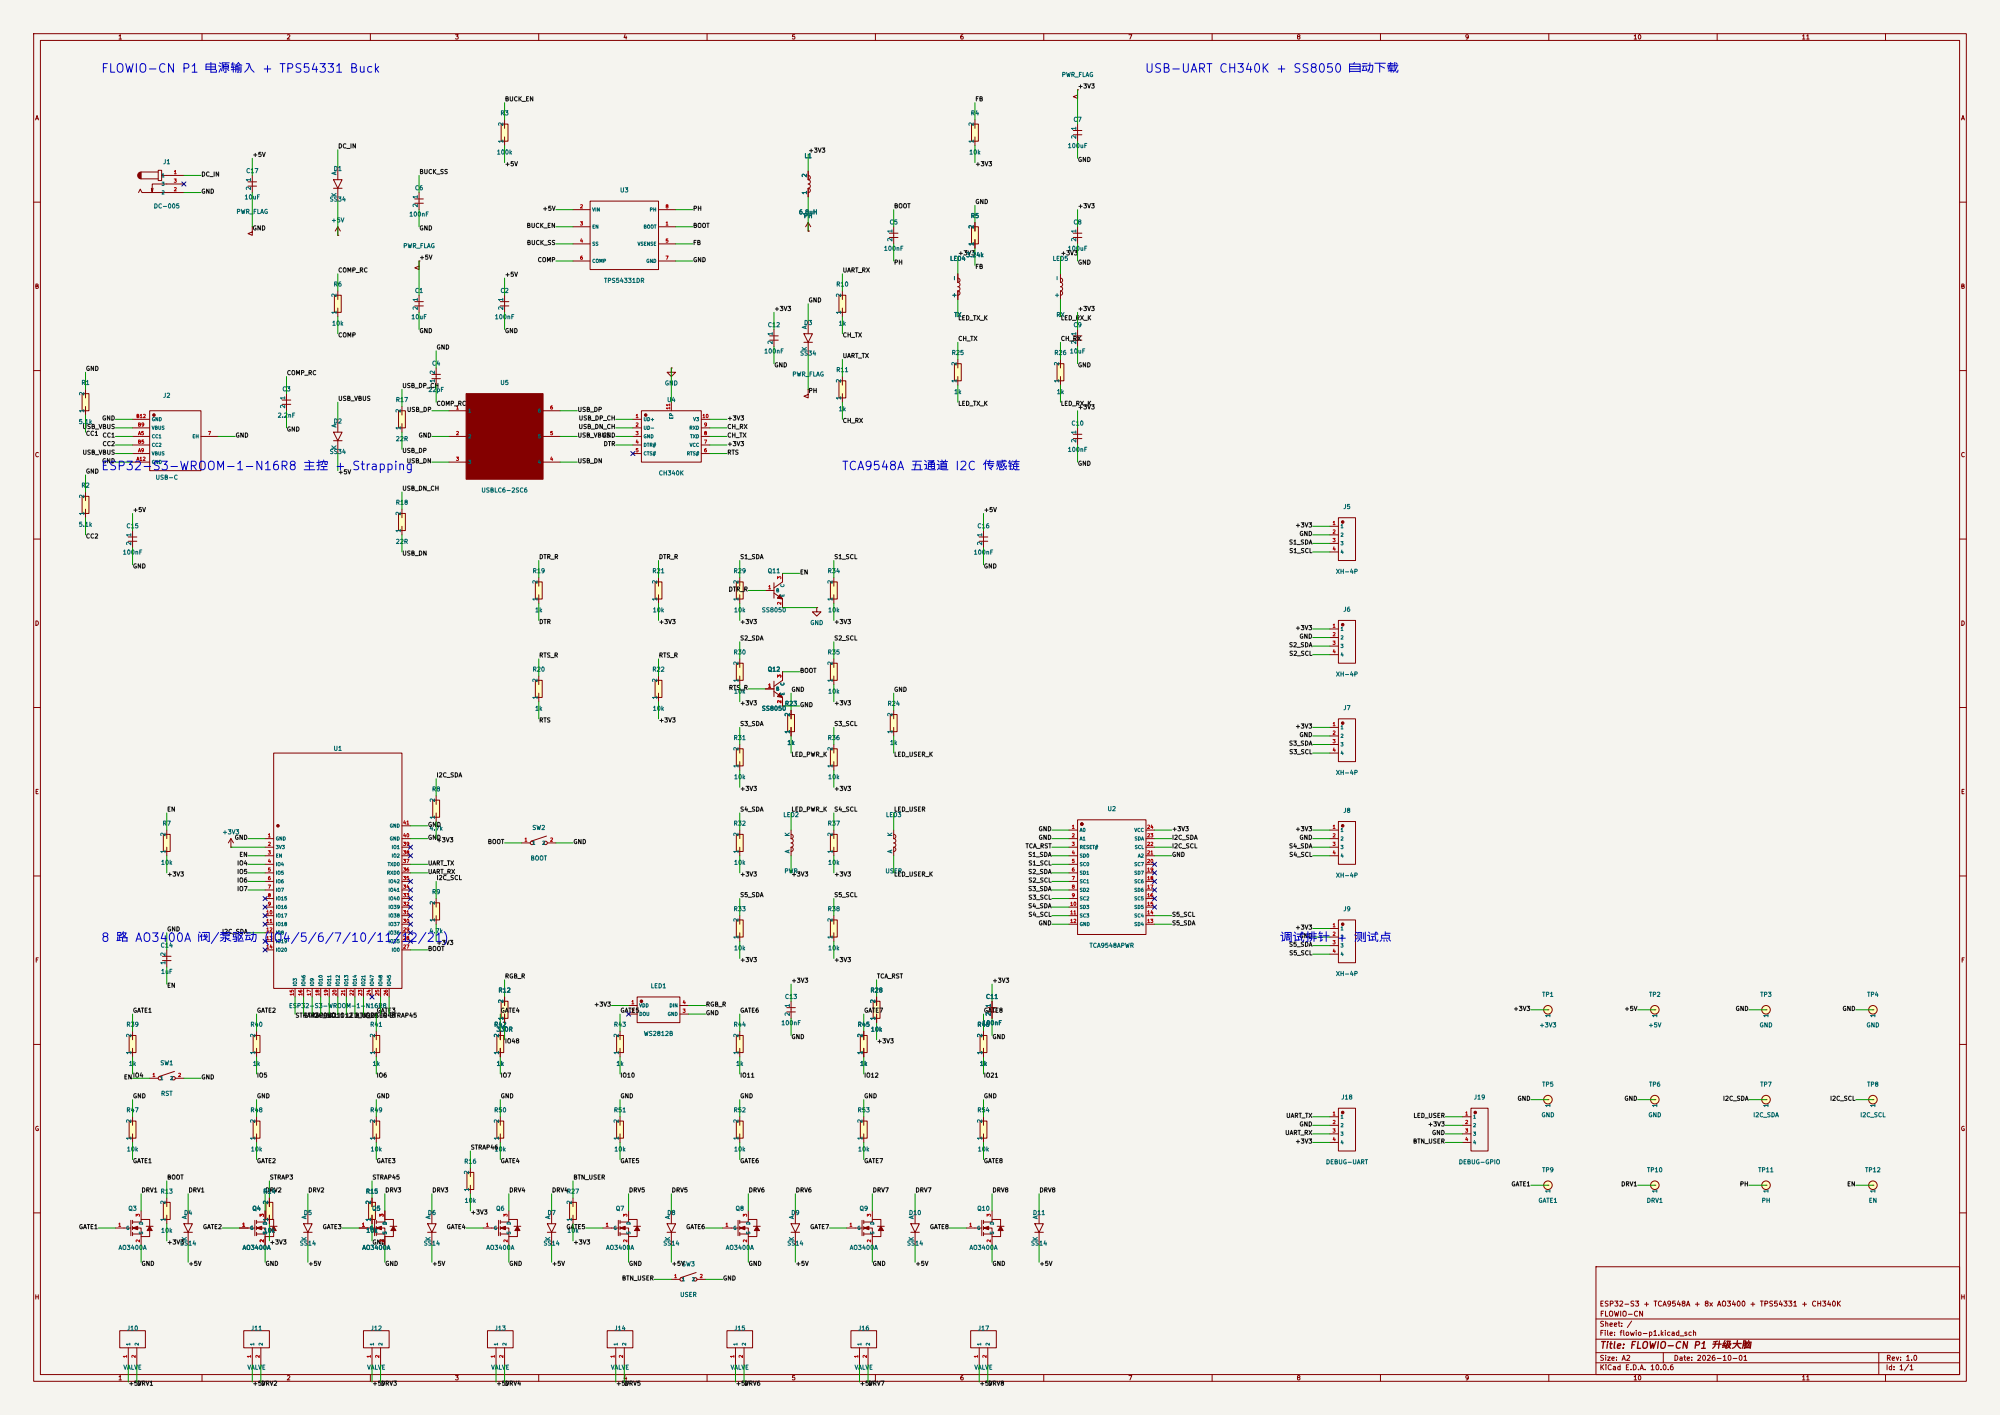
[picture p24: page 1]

FLOWIO-CN P1 电源输入 + TPS54331 Buck

Size: A2 | Rev: 1.0
KiCad E.D.A. 10.0.6 | Id: 1/1

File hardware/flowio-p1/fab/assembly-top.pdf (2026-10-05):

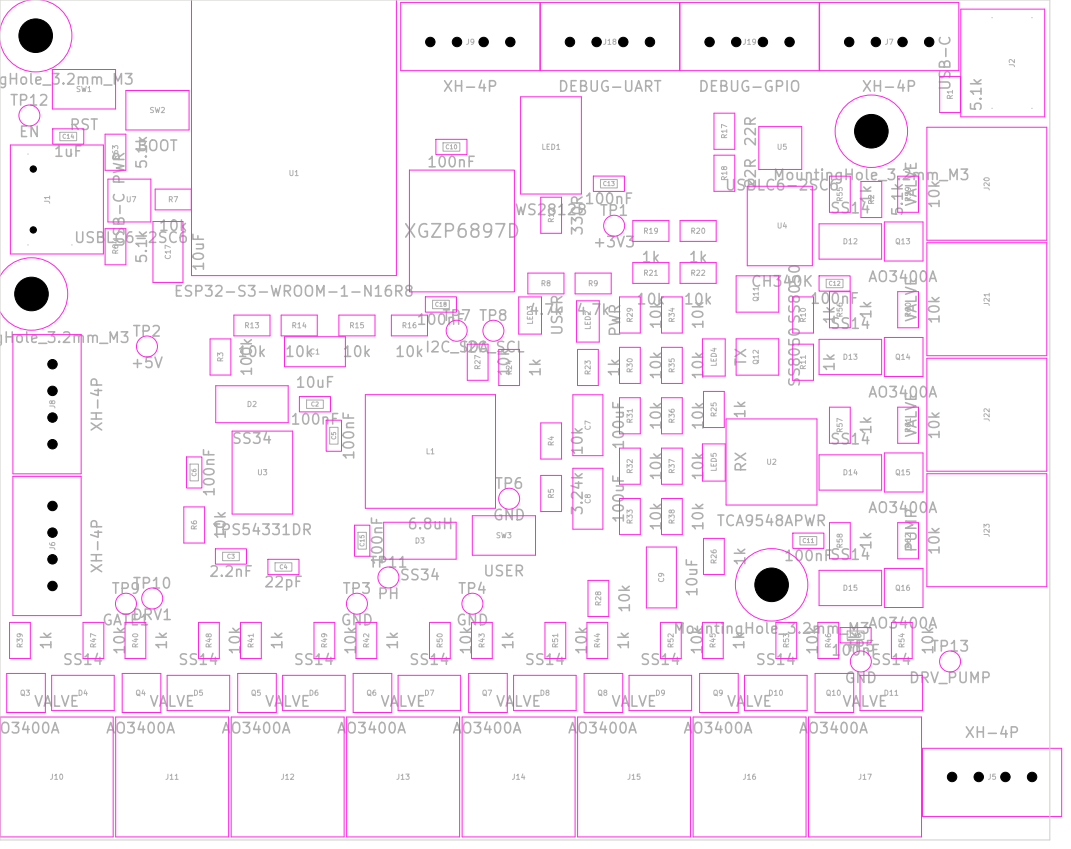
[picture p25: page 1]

AO3400A | | J14 AO3400A | J15 VALVE

VALVE | VALVE

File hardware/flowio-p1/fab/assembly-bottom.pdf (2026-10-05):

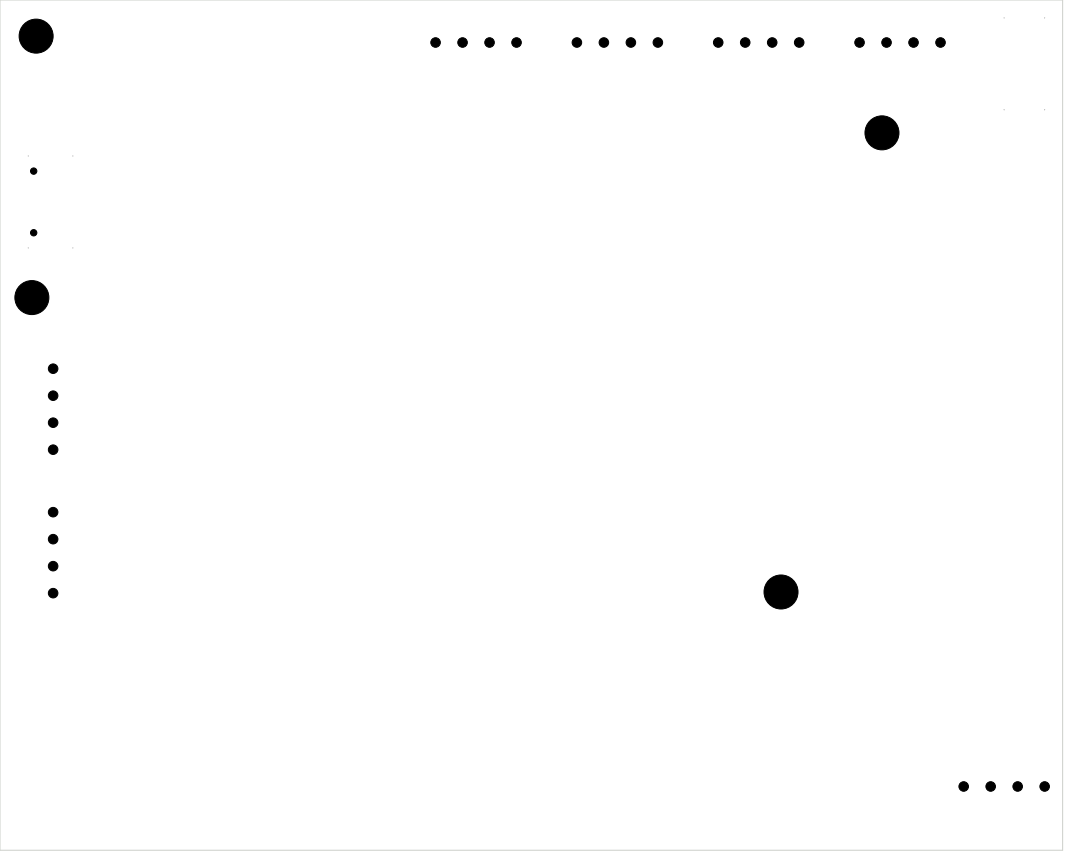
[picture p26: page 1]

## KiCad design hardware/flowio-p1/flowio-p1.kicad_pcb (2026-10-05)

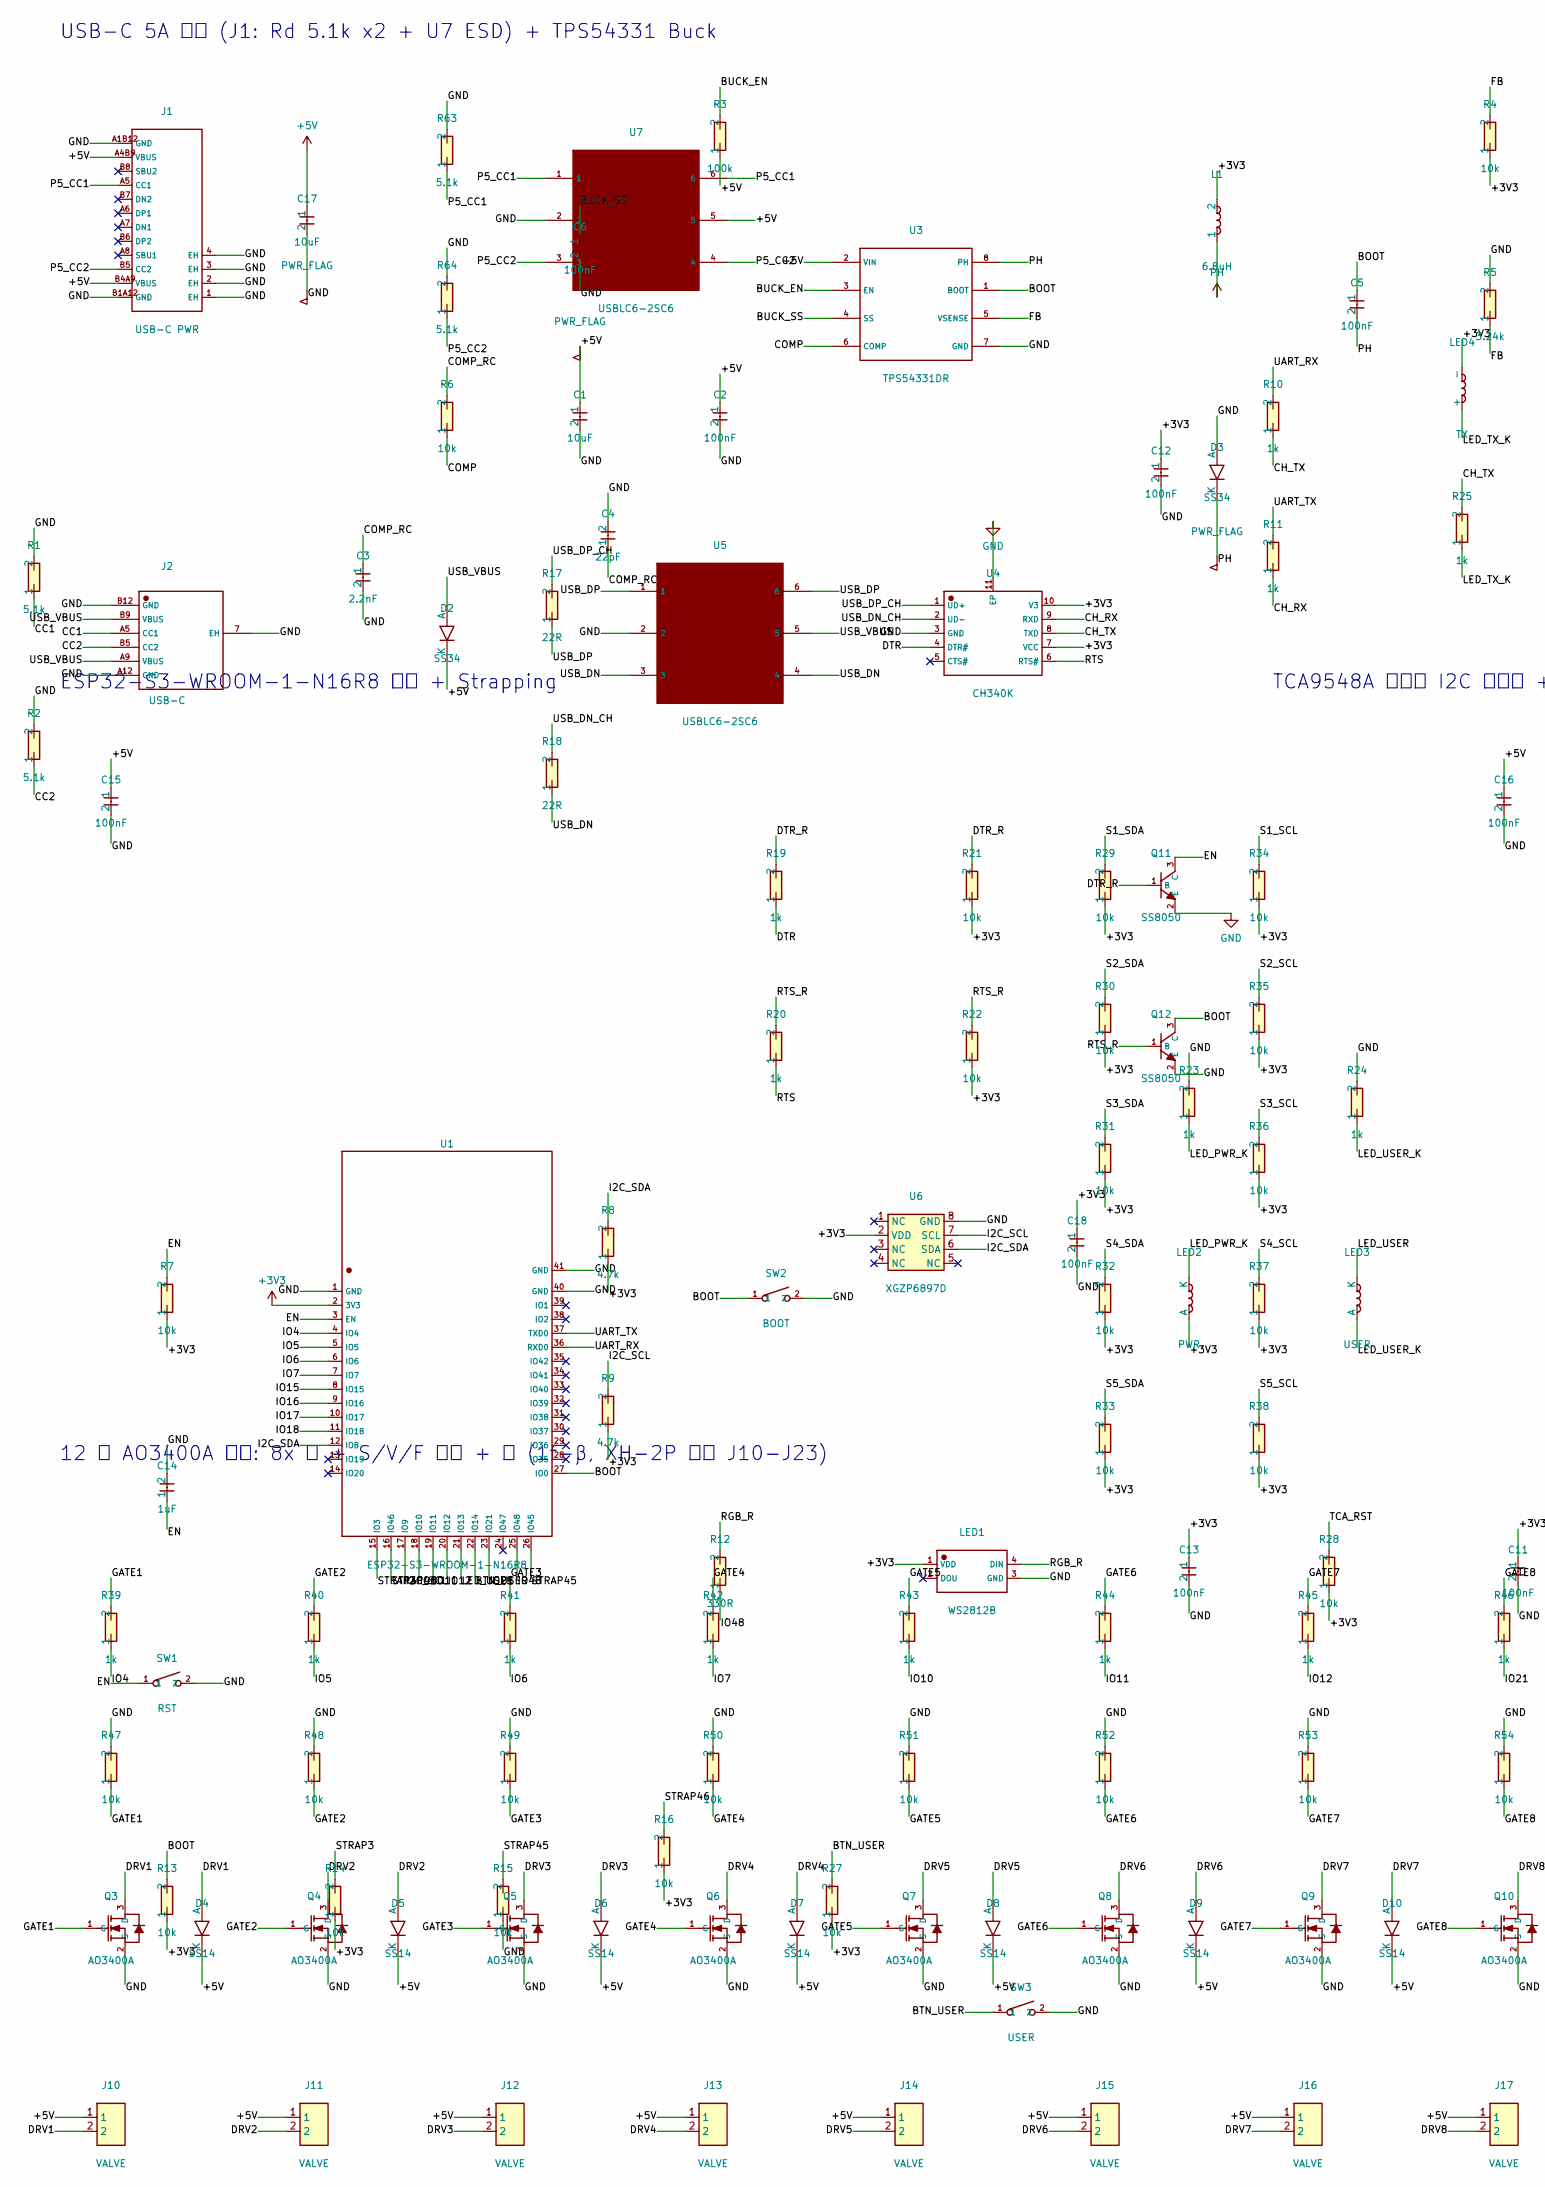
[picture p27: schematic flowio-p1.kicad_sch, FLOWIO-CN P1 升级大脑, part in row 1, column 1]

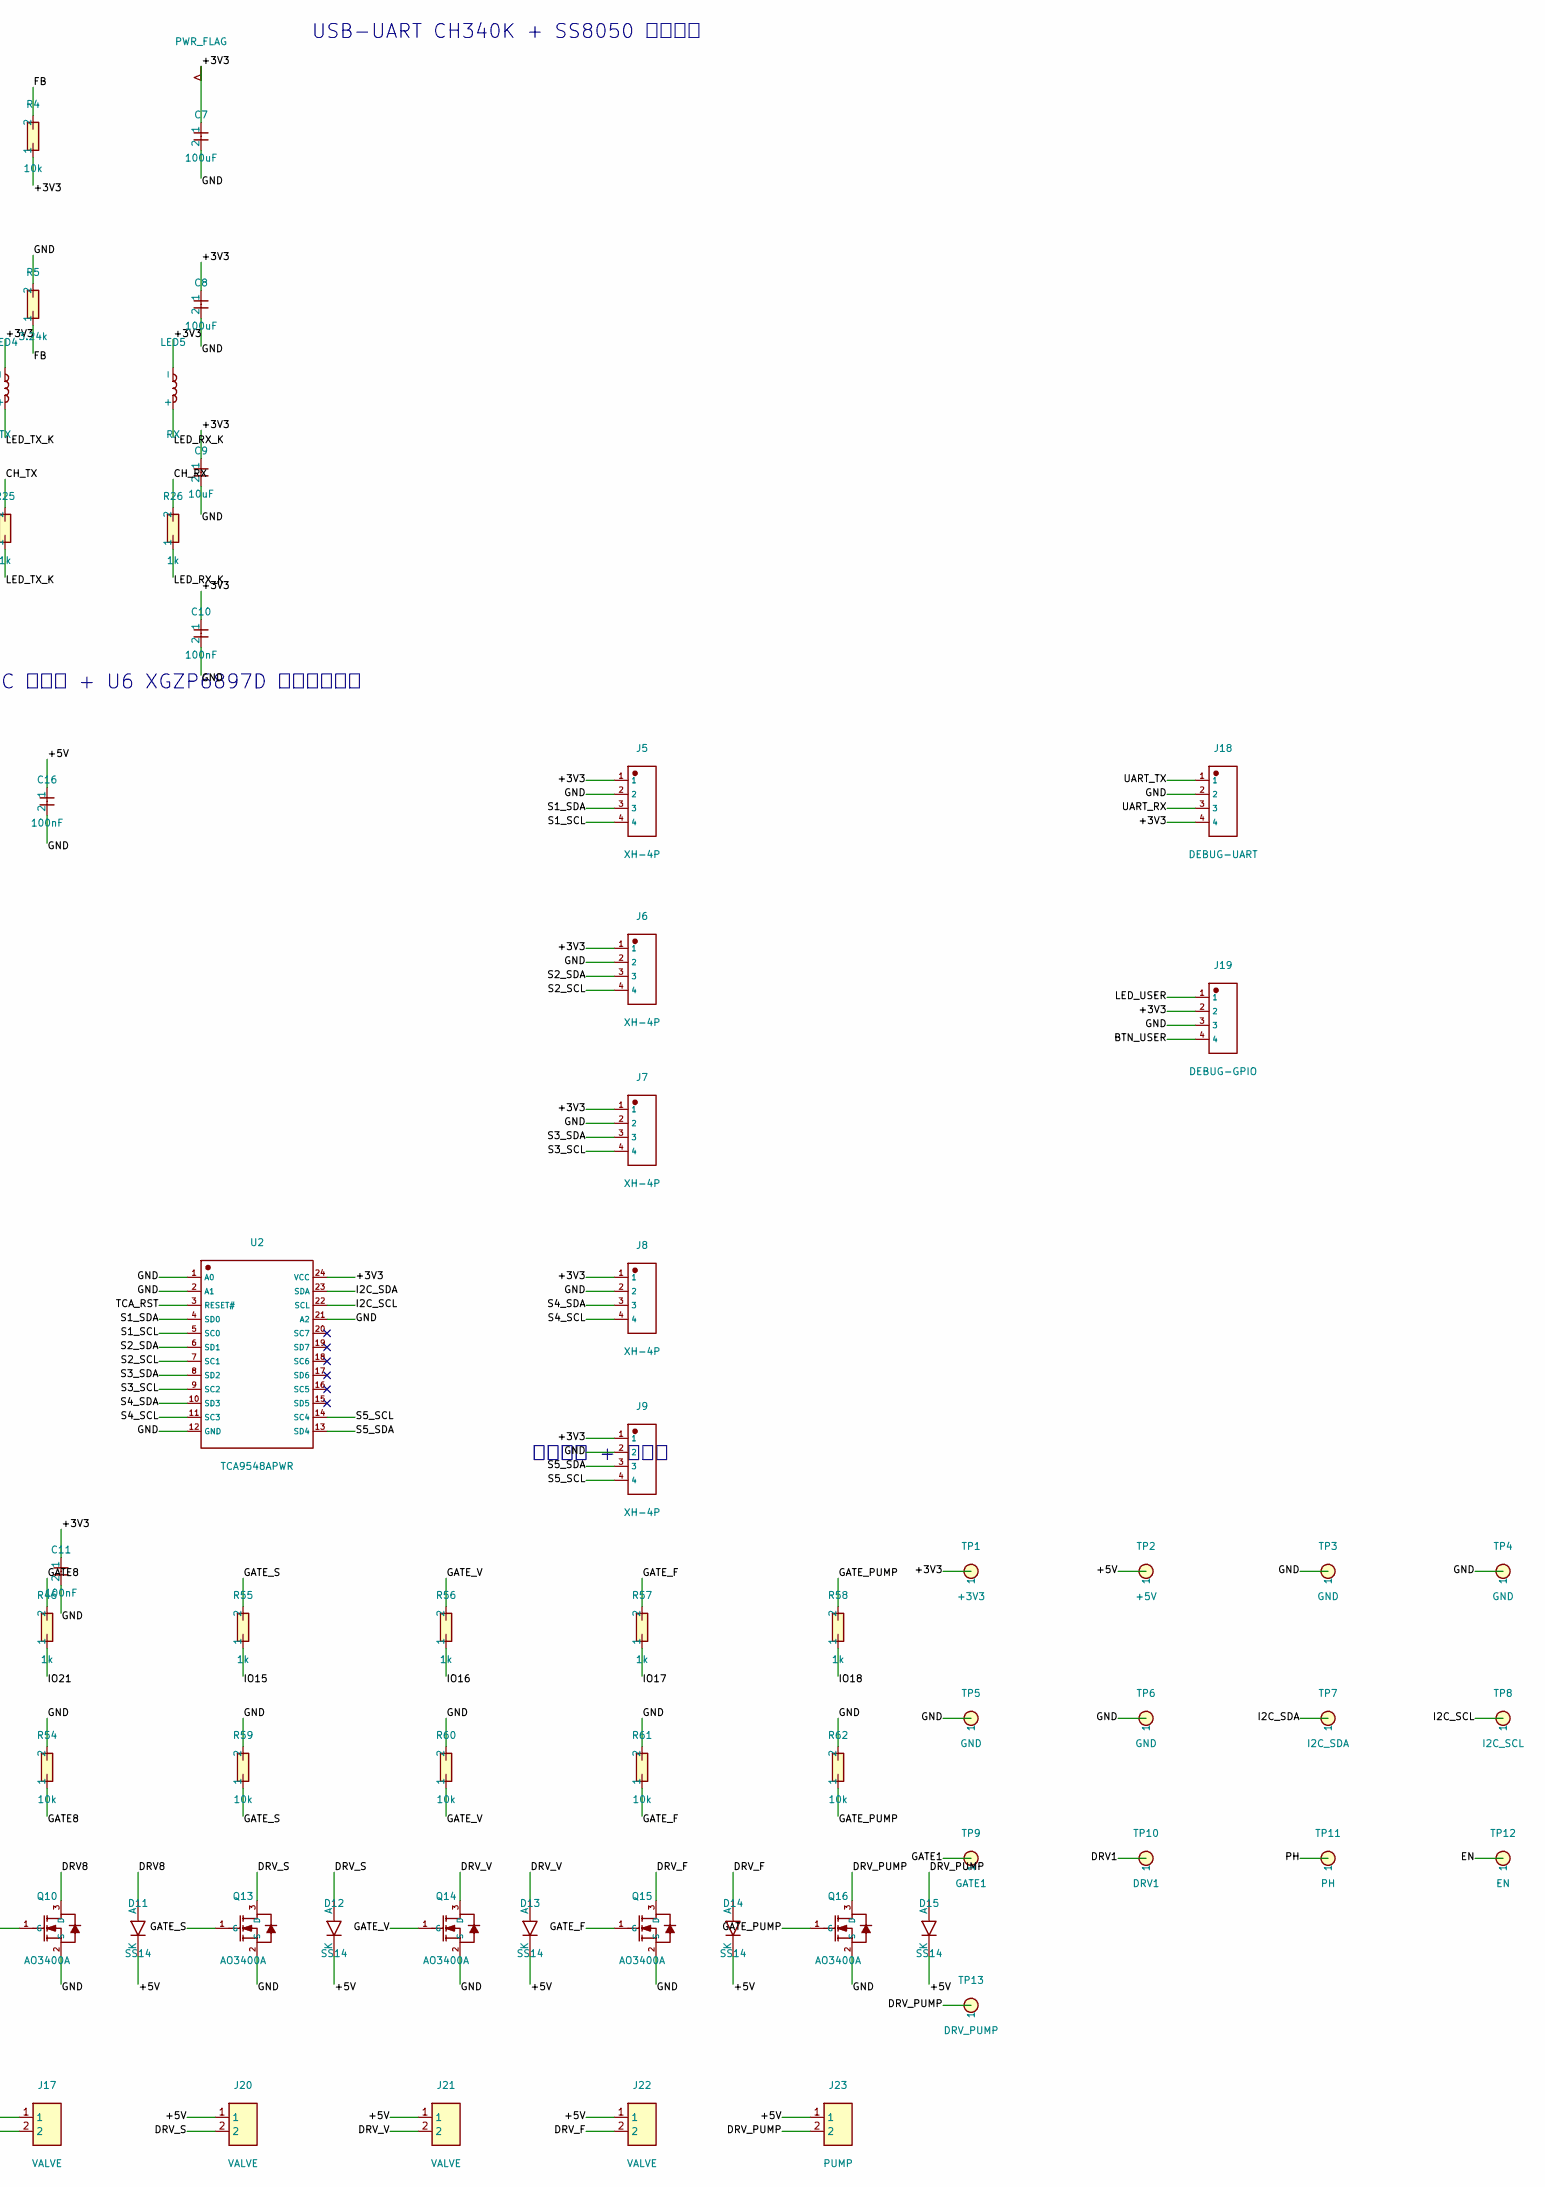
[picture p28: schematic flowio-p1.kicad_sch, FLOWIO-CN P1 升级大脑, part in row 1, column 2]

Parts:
C1, C9, C17: 10uF; C1206; LCSC C13585
C2, C5, C6, C10, C11, C12, C13, C15, C16, C18: 100nF; C_0603_1608Metric; LCSC C1591
C3: 2.2nF; C_0603_1608Metric; LCSC C33353
C4: 22pF; C_0603_1608Metric; LCSC C1653
C7, C8: 100uF; C1206; LCSC C15008
C14: 1uF; C_0603_1608Metric; LCSC C15849
D2, D3: SS34; SMA_L4.3-W2.6-LS5.2-RD; LCSC C8678
D4, D5, D6, D7, D8, D9, D10, D11, D12, D13, D14, D15: SS14; SMA_L4.2-W2.6-LS5.0-RD_1; LCSC C2480
J1: USB-C PWR; USB-C_SMD-TYPE-C-31-M-12_1; LCSC C165948
J2: USB-C; TYPE-C-SMD_TYPE-C-6P_1; LCSC C456012
J5, J6, J7, J8, J9: XH-4P; CONN-TH_4P-P2.54_6173868; LCSC C5359632
J10, J11, J12, J13, J14, J15, J16, J17, J20, J21, J22: VALVE; CONN-SMD_2P-P2.54_MEGASTAR_ZX-XH2.54-2PWT; LCSC C7429671
J18: DEBUG-UART; CONN-TH_4P-P2.54_6173868; LCSC C5359632
J19: DEBUG-GPIO; CONN-TH_4P-P2.54_6173868; LCSC C5359632
J23: PUMP; CONN-SMD_2P-P2.54_MEGASTAR_ZX-XH2.54-2PWT; LCSC C7429671
L1: 6.8uH; IND-SMD_L10.2-W10.0; LCSC C167253
LED1: WS2812B; LED-SMD_4P-L5.0-W5.0-BL_XL-5050RGBC; LCSC C2843785
LED2: PWR; LED-SMD_L1.6-W0.8-R-RD; LCSC C2286
LED3: USER; LED0603-RD; LCSC C2288
LED4: TX; LED0603-RD-YELLOW; LCSC C125100
LED5: RX; LED0603-RD-YELLOW; LCSC C125100
Q3, Q4, Q5, Q6, Q7, Q8, Q9, Q10, Q13, Q14, Q15, Q16: AO3400A; SOT-23-3_L2.9-W1.3-P1.90-LS2.4-BR; LCSC C20917
Q11, Q12: SS8050; SOT-23-3_L3.0-W1.3-P1.90-LS2.5-BR; LCSC C181160
R1, R2, R63, R64: 5.1k; R0603; LCSC C23186
R3: 100k; R0603; LCSC C14675
R4, R6, R7, R13, R14, R15, R16, R21, R22, R27, R28, R29, R30, R31, R32, R33, R34, R35, R36, R37, R38, R47, R48, R49, R50, R51, R52, R53, R54, R59, R60, R61, R62: 10k; R0603; LCSC C25804
R5: 3.24k; R0603; LCSC C22994
R8, R9: 4.7k; R0603; LCSC C23162
R10, R11, R19, R20, R23, R24, R25, R26, R39, R40, R41, R42, R43, R44, R45, R46, R55, R56, R57, R58: 1k; R0603; LCSC C21190
R12: 330R; R0603; LCSC C23138
R17, R18: 22R; R0603; LCSC C23345
SW1: RST; SW-SMD_ST-1185S; LCSC C589191
SW2: BOOT; SW-SMD_ST-1185S; LCSC C589191
SW3: USER; SW-SMD_ST-1185S; LCSC C589191
TP1: +3V3; TestPoint_Pad_D1.0mm
TP2: +5V; TestPoint_Pad_D1.0mm
TP3, TP4, TP5, TP6: GND; TestPoint_Pad_D1.0mm
TP7: I2C_SDA; TestPoint_Pad_D1.0mm
TP8: I2C_SCL; TestPoint_Pad_D1.0mm
TP9: GATE1; TestPoint_Pad_D1.0mm
TP10: DRV1; TestPoint_Pad_D1.0mm
TP11: PH; TestPoint_Pad_D1.0mm
TP12: EN; TestPoint_Pad_D1.0mm
TP13: DRV_PUMP; TestPoint_Pad_D1.0mm
U1: ESP32-S3-WROOM-1-N16R8; WIRELM-SMD_ESP32-S3-WROOM-1; LCSC C2913202
U2: TCA9548APWR; TSSOP-24_L7.8-W4.4-P0.65-LS6.4-BL; LCSC C130026
U3: TPS54331DR; SOIC-8_L5.0-W4.0-P1.27-LS6.0-BL; LCSC C9865
U4: CH340K; ESOP-10_L4.9-W3.9-P1.00-LS6.2-BL-EP; LCSC C968586
U5, U7: USBLC6-2SC6; SOT-23-6_L2.9-W1.6-P0.95-LS2.8-BL; LCSC C7519
U6: XGZP6897D; XGZP6897D-SOP8-W7.96-P2.54

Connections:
+3V3: C7.1, C8.1, C9.1, C10.1, C11.1, C12.1, C13.1, C18.1, J5.1, J6.1, J7.1, J8.1, J9.1, J18.4, J19.2, L1.2, LED1.1 (VDD), LED2.1 (A), LED4.1 (-), LED5.1 (-), R4.1, R7.1, R8.1, R9.1, R13.1, R14.1, R16.1, R21.1, R22.1, R27.1, R28.1, R29.1, R30.1, R31.1, R32.1, R33.1, R34.1, R35.1, R36.1, R37.1, R38.1, TP1.1, U1.2 (3V3), U2.24 (VCC), U4.7 (VCC), U4.10 (V3), U6.2 (VDD)
+5V: C1.1, C2.1, C15.1, C16.1, C17.1, D2.1 (K), D4.1 (K), D5.1 (K), D6.1 (K), D7.1 (K), D8.1 (K), D9.1 (K), D10.1 (K), D11.1 (K), D12.1 (K), D13.1 (K), D14.1 (K), D15.1 (K), J1.A4B9 (VBUS), J1.B4A9 (VBUS), J10.1, J11.1, J12.1, J13.1, J14.1, J15.1, J16.1, J17.1, J20.1, J21.1, J22.1, J23.1, R3.1, TP2.1, U3.2 (VIN), U7.5
BOOT: C5.1, Q12.3 (C), R13.2, SW2.1, U1.27 (IO0), U3.1 (BOOT)
BTN_USER: J19.4, R27.2, SW3.1, U1.22 (IO14)
BUCK_EN: R3.2, U3.3 (EN)
BUCK_SS: C6.1, U3.4 (SS)
CC1: J2.A5 (CC1), R1.1
CC2: J2.B5 (CC2), R2.1
CH_RX: R11.1, R26.2, U4.9 (RXD)
CH_TX: R10.1, R25.2, U4.8 (TXD)
COMP: R6.1, U3.6 (COMP)
COMP_RC: C3.1, C4.1, R6.2
DRV1: D4.2 (A), J10.2, Q3.3 (D), TP10.1
DRV2: D5.2 (A), J11.2, Q4.3 (D)
DRV3: D6.2 (A), J12.2, Q5.3 (D)
DRV4: D7.2 (A), J13.2, Q6.3 (D)
DRV5: D8.2 (A), J14.2, Q7.3 (D)
DRV6: D9.2 (A), J15.2, Q8.3 (D)
DRV7: D10.2 (A), J16.2, Q9.3 (D)
DRV8: D11.2 (A), J17.2, Q10.3 (D)
DRV_F: D14.2 (A), J22.2, Q15.3 (D)
DRV_PUMP: D15.2 (A), J23.2, Q16.3 (D), TP13.1
DRV_S: D12.2 (A), J20.2, Q13.3 (D)
DRV_V: D13.2 (A), J21.2, Q14.3 (D)
DTR: R19.1, U4.4 (DTR#)
DTR_R: Q11.1 (B), R19.2, R21.2
EN: C14.1, Q11.3 (C), R7.2, SW1.1, TP12.1, U1.3 (EN)
FB: R4.2, R5.1, U3.5 (VSENSE)
GATE1: Q3.1 (G), R39.2, R47.1, TP9.1
GATE2: Q4.1 (G), R40.2, R48.1
GATE3: Q5.1 (G), R41.2, R49.1
GATE4: Q6.1 (G), R42.2, R50.1
GATE5: Q7.1 (G), R43.2, R51.1
GATE6: Q8.1 (G), R44.2, R52.1
GATE7: Q9.1 (G), R45.2, R53.1
GATE8: Q10.1 (G), R46.2, R54.1
GATE_F: Q15.1 (G), R57.2, R61.1
GATE_PUMP: Q16.1 (G), R58.2, R62.1
GATE_S: Q13.1 (G), R55.2, R59.1
GATE_V: Q14.1 (G), R56.2, R60.1
GND: C1.2, C2.2, C3.2, C4.2, C6.2, C7.2, C8.2, C9.2, C10.2, C11.2, C12.2, C13.2, C14.2, C15.2, C16.2, C17.2, C18.2, D3.2 (A), J1.1 (EH), J1.2 (EH), J1.3 (EH), J1.4 (EH), J1.A1B12 (GND), J1.B1A12 (GND), J2.7 (EH), J2.A12 (GND), J2.B12 (GND), J5.2, J6.2, J7.2, J8.2, J9.2, J18.2, J19.3, LED1.3 (GND), Q3.2 (S), Q4.2 (S), Q5.2 (S), Q6.2 (S), Q7.2 (S), Q8.2 (S), Q9.2 (S), Q10.2 (S), Q11.2 (E), Q12.2 (E), Q13.2 (S), Q14.2 (S), Q15.2 (S), Q16.2 (S), R1.2, R2.2, R5.2, R15.1, R23.2, R24.2, R47.2, R48.2, R49.2, R50.2, R51.2, R52.2, R53.2, R54.2, R59.2, R60.2, R61.2, R62.2, R63.2, R64.2, SW1.2, SW2.2, SW3.2, TP3.1, TP4.1, TP5.1, TP6.1, U1.1 (GND), U1.40 (GND), U1.41 (GND), U2.1 (A0), U2.2 (A1), U2.12 (GND), U2.21 (A2), U3.7 (GND), U4.3 (GND), U4.11 (EP), U5.2, U6.8 (GND), U7.2
I2C_SCL: R9.2, TP8.1, U1.17 (IO9), U2.22 (SCL), U6.7 (SCL)
I2C_SDA: R8.2, TP7.1, U1.12 (IO8), U2.23 (SDA), U6.6 (SDA)
IO4: R39.1, U1.4 (IO4)
IO5: R40.1, U1.5 (IO5)
IO6: R41.1, U1.6 (IO6)
IO7: R42.1, U1.7 (IO7)
IO10: R43.1, U1.18 (IO10)
IO11: R44.1, U1.19 (IO11)
IO12: R45.1, U1.20 (IO12)
IO15: R55.1, U1.8 (IO15)
IO16: R56.1, U1.9 (IO16)
IO17: R57.1, U1.10 (IO17)
IO18: R58.1, U1.11 (IO18)
IO21: R46.1, U1.23 (IO21)
IO48: R12.1, U1.25 (IO48)
LED_PWR_K: LED2.2 (K), R23.1
LED_RX_K: LED5.2 (+), R26.1
LED_TX_K: LED4.2 (+), R25.1
LED_USER: J19.1, LED3.1 (K), U1.21 (IO13)
LED_USER_K: LED3.2 (A), R24.1
P5_CC1: J1.A5 (CC1), R63.1, U7.1, U7.6
P5_CC2: J1.B5 (CC2), R64.1, U7.3, U7.4
PH: C5.2, D3.1 (K), L1.1, TP11.1, U3.8 (PH)
RGB_R: LED1.4 (DIN), R12.2
RTS: R20.1, U4.6 (RTS#)
RTS_R: Q12.1 (B), R20.2, R22.2
S1_SCL: J5.4, R34.2, U2.5 (SC0)
S1_SDA: J5.3, R29.2, U2.4 (SD0)
S2_SCL: J6.4, R35.2, U2.7 (SC1)
S2_SDA: J6.3, R30.2, U2.6 (SD1)
S3_SCL: J7.4, R36.2, U2.9 (SC2)
S3_SDA: J7.3, R31.2, U2.8 (SD2)
S4_SCL: J8.4, R37.2, U2.11 (SC3)
S4_SDA: J8.3, R32.2, U2.10 (SD3)
S5_SCL: J9.4, R38.2, U2.14 (SC4)
S5_SDA: J9.3, R33.2, U2.13 (SD4)
STRAP3: R14.2, U1.15 (IO3)
STRAP45: R15.2, U1.26 (IO45)
STRAP46: R16.2, U1.16 (IO46)
TCA_RST: R28.2, U2.3 (RESET#)
UART_RX: J18.3, R10.2, U1.36 (RXD0)
UART_TX: J18.1, R11.2, U1.37 (TXD0)
USB_DN: R18.1, U5.3, U5.4
USB_DN_CH: R18.2, U4.2 (UD-)
USB_DP: R17.1, U5.1, U5.6
USB_DP_CH: R17.2, U4.1 (UD+)
USB_VBUS: D2.2 (A), J2.A9 (VBUS), J2.B9 (VBUS), U5.5

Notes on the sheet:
USB-C 5A 供电 (J1: Rd 5.1k x2 + U7 ESD) + TPS54331 Buck
USB-UART CH340K + SS8050 自动下载
ESP32-S3-WROOM-1-N16R8 主控 + Strapping
TCA9548A 五通道 I2C 传感链 + U6 XGZP6897D 板载压力传感
12 路 AO3400A 驱动: 8x 阀 + S/V/F 主阀 + 泵 (1f-β, XH-2P 插座 J10-J23)
调试排针 + 测试点

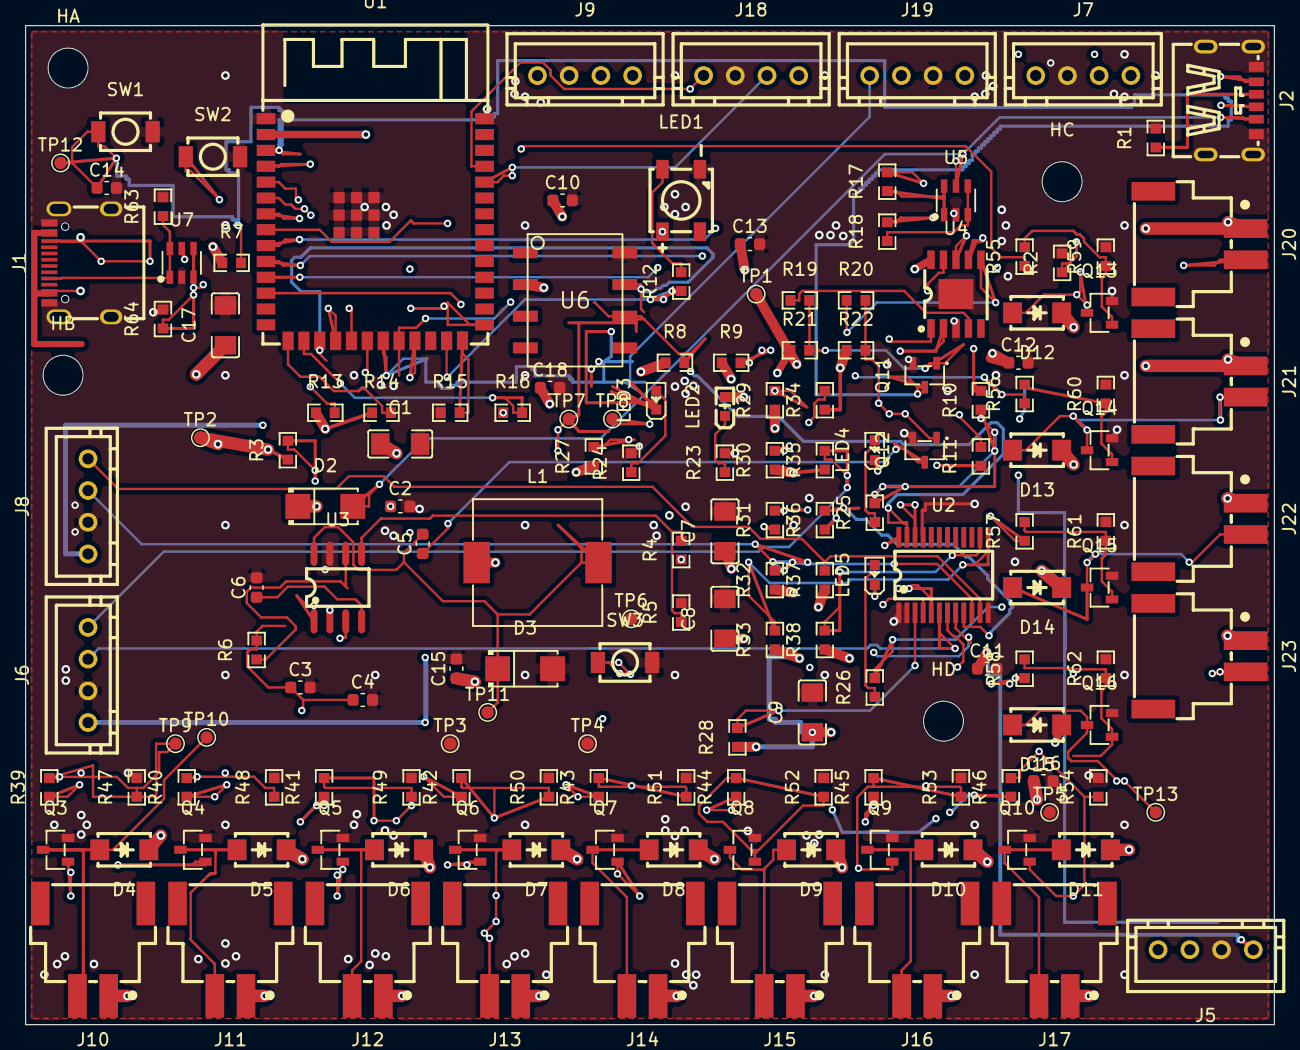
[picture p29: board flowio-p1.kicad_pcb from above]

Board: 4 copper layers, 100.0 x 80.0 mm, 164 parts (0 on the bottom side), 88 nets.

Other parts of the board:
HA: MountingHole_3.2mm_M3
HB: MountingHole_3.2mm_M3
HC: MountingHole_3.2mm_M3
HD: MountingHole_3.2mm_M3

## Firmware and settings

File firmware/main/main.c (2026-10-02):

/**
 * main.c — P0 上电入口（目标机）
 *
 * 架构：control_task 以 10ms 周期跑（闭环 tick + 节能 + 超压保护 + 泵护栏
 *       + BLE 遥测组帧）；命令入口统一为 pn_cmd_feed()（S5 cmd_transport）：
 *       串口 fgets 与 BLE cmd 特征（经 ble_twin 队列任务）喂同一函数，
 *       行缓冲聚合 + 0xA5 帧翻译后走 pn_core/cli.c 分发（与虚拟设备共用）。
 */
#include "pn_core/actions.h"
#include "pn_core/closedloop.h"
#include "pn_core/cli.h"
#include "pn_core/proto.h"      /* S5: 0xA5 帧命令翻译（BLE cmd 特征） */
#include "pn_core/tca9548.h"    /* S4: tca_bind 注入真机 I2C 写 */
#include "pn_hal_esp32/hal_esp32.h"
#include "pn_hal_esp32/ble_twin.h"

#include "freertos/FreeRTOS.h"
#include "freertos/task.h"
#include "freertos/semphr.h"
#include "driver/uart.h"
#include "driver/uart_vfs.h"
#include "driver/gpio.h"
#include "esp_timer.h"
#include <stdio.h>
#include <string.h>

/* 充电宝/电池独立供电时无串口对端，上电自动跑呼吸演示循环（充→停→抽→停）。
 * 串口调试时按住 BOOT 键开机可禁用演示（GPIO0 拉低即跳过），
 * 否则演示会周期性改变阀/传感状态干扰测试。置 0 永久关闭。 */
#define PN_BOOT_DEMO 1

static void cli_delay_wrapper(uint32_t ms) { vTaskDelay(pdMS_TO_TICKS(ms)); }

/* ---------- cmd_transport 统一分发（S5，BLE.md §1/§3.2） ----------
 * 串口 fgets 与 BLE cmd write 都喂 pn_cmd_feed()：字节流先按 0xA5 二进制帧
 * 或 ASCII 行聚合（跨多次 write 分片的行也能拼上），完整后翻译成 CLI 行，
 * 与串口走同一个 pn_cli_process_line()。互斥锁串行化三个调用线程
 * （串口主循环 / BLE cmd 任务 / 演示任务）。 */
static SemaphoreHandle_t s_cmd_mtx;
static char     s_line[64];
static size_t   s_line_n;
static uint8_t  s_frame[5];
static size_t   s_frame_n;
static bool     s_in_frame;

static void dispatch_line(char *line)
{
    if (line[0] == 'W' && line[1] == 0)
        pn_hal_esp32_i2c_scan();   /* bring-up 诊断：I2C 全总线扫描 */
    else if (line[0] == 'M') {
        /* 舵机诊断：M <gpio> <usec> —— LEDC 精确时基发 50Hz 舵机脉冲 */
        int gpio = 17, usec = 2500;
        if (sscanf(line + 1, "%d %d", &gpio, &usec) >= 1)
            pn_hal_esp32_servo_le_test(gpio, usec);
    }
    else
        pn_cli_process_line(line);
}

/* 0xA5 帧 → 等价 CLI 行（BLE.md §3.2 翻译表；CRC 已在调用处校验） */
static void frame_to_line(const uint8_t f[5], char *out, size_t cap)
{
    switch ((char)f[1]) {
    case PN_CMD_INFLATE: snprintf(out, cap, "I %u %u", f[2], f[3]); break;
    case PN_CMD_VACUUM:  snprintf(out, cap, "V %u %u", f[2], f[3]); break;
    case PN_CMD_RELEASE: snprintf(out, cap, "R %u", f[2]);          break;
    case PN_CMD_STOP:    snprintf(out, cap, "S %u", f[2]);          break;
    case PN_CMD_OPEN:    snprintf(out, cap, "O %u", f[2]);          break;
    case PN_CMD_CLOSE:   snprintf(out, cap, "C %u", f[2]);          break;
    case PN_CMD_QUERY:   snprintf(out, cap, "P");                   break;
    case PN_CMD_STATE:   snprintf(out, cap, "T");                   break;
    case PN_CMD_RESET:   snprintf(out, cap, "X");                   break;
    default:             snprintf(out, cap, "?");                   break;
    }
}

void pn_cmd_feed(const uint8_t *buf, size_t len)
{
    char cooked[24];
    for (size_t i = 0; i < len; ++i) {
        uint8_t b = buf[i];

        /* 二进制帧模式：行缓冲空时见 0xA5 进入，收满 5 字节校验后翻译 */
        if (s_in_frame || (b == PN_PROTO_MAGIC && s_line_n == 0 && s_frame_n == 0)) {
            s_in_frame = true;
            s_frame[s_frame_n++] = b;
            if (s_frame_n < sizeof(s_frame)) continue;
            s_frame_n = 0;
            s_in_frame = false;
            if (s_frame[4] == pn_proto_crc8(s_frame, 4)) {   /* 坏帧静默丢弃 */
                frame_to_line(s_frame, cooked, sizeof(cooked));
                xSemaphoreTake(s_cmd_mtx, portMAX_DELAY);
                dispatch_line(cooked);
                xSemaphoreGive(s_cmd_mtx);
            }
            continue;
        }

        if (b == '\n' || b == '\r') {
            if (s_line_n) {
                s_line[s_line_n] = 0;
                s_line_n = 0;
                xSemaphoreTake(s_cmd_mtx, portMAX_DELAY);
                dispatch_line(s_line);
                xSemaphoreGive(s_cmd_mtx);
            }
            continue;
        }
        if (s_line_n < sizeof(s_line) - 1)
            s_line[s_line_n++] = (char)b;
        else
            s_line_n = 0;   /* 超长行整行丢弃（BLE.md：命令行 ≤63B） */
    }
}

#if PN_BOOT_DEMO
static void demo_task(void *arg)
{
    (void)arg;
    /* 上电后 30 秒内按住 BOOT（GPIO0 拉低）≥1 秒 → 本次跳过演示；
     * 30 秒后未按 → 自动开始呼吸演示循环（充电宝独立供电场景）。
     * 注意：复位瞬间不要按 BOOT（GPIO0 采样低会进下载模式挂起）——
     * 复位完成后再按。 */
    gpio_config_t io = {
        .pin_bit_mask = 1ULL << GPIO_NUM_0,
        .mode = GPIO_MODE_INPUT,
        .pull_up_en = GPIO_PULLUP_ENABLE,
    };
    gpio_config(&io);
    for (int i = 0; i < 600; ++i) {   /* 30s = 600×50ms */
        if (gpio_get_level(GPIO_NUM_0) == 0) {
            printf("[DEMO] BOOT held — demo disabled this session\n");
            vTaskDelete(NULL);
        }
        vTaskDelay(pdMS_TO_TICKS(50));
    }
    printf("[DEMO] breathing demo: I 6s -> S 3s -> V 6s -> S 3s loop\n");
    for (;;) {
        pn_cmd_feed((const uint8_t *)"I 1 255\n", 8);    /* 充气 */
        vTaskDelay(pdMS_TO_TICKS(6000));
        pn_cmd_feed((const uint8_t *)"S 1\n", 4);        /* 停止保压 */
        vTaskDelay(pdMS_TO_TICKS(3000));
        pn_cmd_feed((const uint8_t *)"V 1 255\n", 8);    /* 抽气 */
        vTaskDelay(pdMS_TO_TICKS(6000));
        pn_cmd_feed((const uint8_t *)"S 1\n", 4);
        vTaskDelay(pdMS_TO_TICKS(3000));
    }
}
#endif

static void control_task(void *arg)
{
    (void)arg;
    uint32_t pump_on_since = 0;
    for (;;) {
        pn_cl_status_t cl = pn_inflate_to_tick();
        if (cl == PN_CL_DONE) {
            pn_inflate_job_t j;
            pn_inflate_to_get_job(&j);
            printf("[CL] done elapsed=%ums reached=%.1fkPa\n",
                   (unsigned)j.elapsed_ms, (double)j.reached_kpa);
        } else if (cl == PN_CL_TIMEOUT) {
            printf("[CL] timeout, aborted\n");
        } else if (cl == PN_CL_ERR) {
            printf("[CL] sensor error, aborted\n");
        }

        /* 泵连续运行护栏：超时强制停止（防干转/过热） */
        if (pn_get_state_of(7)) {
            uint32_t now_ms = (uint32_t)(esp_timer_get_time() / 1000);
            if (pump_on_since == 0) pump_on_since = now_ms;
            else if (now_ms - pump_on_since > 120000u) {
                pn_pump_stop();
                printf("[SAFETY] pump max runtime, stopped\n");
                pump_on_since = 0;
            }
        } else pump_on_since = 0;

        pn_optimize_power(ble_twin_hold_duty(), ble_twin_hold_delay_ms());  /* S5: Config 服务 RAM 镜像（默认值=原宏） */
        pn_check_overpressure(120.f);
        pn_hal_esp32_servo_refresh();                           /* 舵机 50Hz 脉冲流（单次发送非循环） */
        board_led_set(pn_get_state() ? 1 : 0);   /* S4 简化映射：任一执行器动作=RUNNING 绿，否则 IDLE 呼吸蓝 */
        board_led_tick_10ms();                   /* WS2812 呼吸/闪烁状态机（10ms 节拍驱动） */
        ble_twin_tick_10ms();                    /* S5: 每 100ms 组 20B state notify（notify_en 开才发） */
        vTaskDelay(pdMS_TO_TICKS(10));
    }
}

void app_main(void)
{
    /* 真机 stdin 需要 UART 驱动 + VFS 桥接（默认 console 只配输出——fgets 收不到；
     * 2026-09-23 真机首次点亮实证。QEMU 的 UART 模型走轮询读，跳过以免驱动中断差异） */
    if (!pn_hal_esp32_is_qemu()) {
        uart_driver_install(CONFIG_ESP_CONSOLE_UART_NUM, 256, 0, 0, NULL, 0);
        uart_vfs_dev_use_driver(CONFIG_ESP_CONSOLE_UART_NUM);
    }
    pn_cli_set_delay_fn(cli_delay_wrapper);
    s_cmd_mtx = xSemaphoreCreateMutex();          /* S5: 命令三入口（串口/BLE/演示）串行化 */
    printf("[BOOT] hal init...\n"); fflush(stdout);
    pn_init(pn_hal_esp32_init(), PN_CFG_GENERAL);
    tca_bind(tca_hal_write);      /* S4: pn_core TCA9548A 逻辑层绑定真机 I2C 写（QEMU 下恒 -1，无害） */
    board_led_init();             /* S4: 板载 WS2812 状态灯（QEMU 无 RMT，内部跳过） */
    ble_twin_init();              /* S5: BLE 四服务（QEMU/无 BT 内部安全跳过） */
    printf("[BOOT] pn_init done\n"); fflush(stdout);
    printf("FlowIO-compatible P0 ready. state=0x%04X\n", (unsigned)pn_get_state());
    fflush(stdout);
#if PN_BOOT_DEMO
    xTaskCreate(demo_task, "pn_demo", 4096, NULL, 4, NULL);
#endif

    xTaskCreate(control_task, "pn_ctrl", 4096, NULL, 5, NULL);

    char line[64];
    for (;;) {
        if (fgets(line, sizeof(line), stdin)) {
            /* S5: 串口与 BLE cmd 特征同一入口（含行尾符，行缓冲在 pn_cmd_feed 内） */
            pn_cmd_feed((const uint8_t *)line, strlen(line));
        }
    }
}

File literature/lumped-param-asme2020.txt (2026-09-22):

Andrew A. Stanley1
Facebook Reality Labs,
10545 Willows Rd.,
Redmond 98052, WA
e-mail: astan@fb.com
Amirhossein Amini
Facebook Reality Labs,
10545 Willows Rd.,
Redmond 98052, WA
Casey Glick
Facebook Reality Labs,
10545 Willows Rd.,
Redmond 98052, WA
Nathan Usevitch
Facebook Reality Labs,
10545 Willows Rd.,
Redmond 98052, WA
Yi/C21git Meng€uc¸
Facebook Reality Labs,
10545 Willows Rd.,
Redmond 98052, WA
Sean J. Keller
Facebook Reality Labs,
10545 Willows Rd.,
Redmond 98052, WA
Lumped-Parameter Response
Time Models for Pneumatic
Circuit Dynamics
Resistor–capacitor (RC) response time models for pressurizing and depressurizing a
pneumatic capacitor (mass accumulator) through a resistor (ﬂow restriction) comprise a
framework to systematically analyze complex ﬂuidic circuits. A model for pneumatic
resistance is derived from a combination of fundamental ﬂuid mechanics and experimen-
tal results. Models describing compressible ﬂuid capacitance are derived from thermody-
namic ﬁrst principles and validated experimentally. The models are combined to derive
the ordinary differential equations that describe the RC dynamics. These equations are
solved analytically for rigid capacitors and numerically for deformable capacitors to
generate pressure response curves as a function of time. The dynamic pressurization and
depressurization response times to reach 63.2 % (or 1 /C0 e
/C0 1) of exponential decay are
validated in simple pneumatic circuits with combinations of ﬂow restrictions ranging
from 100 lm to 1 mm in diameter, source pressures ranging from 5 to 200 kPa, and
capacitor volumes of 0.5 to 16 mL. Our RC models predict the response times, which
range from a few milliseconds to multiple seconds depending on the combination, with a
coefﬁcient of determination of r 2 ¼ 0:983. The utility of the models is demonstrated in a
multicomponent ﬂuidic circuit to ﬁnd the optimal diameter of tubing between a three-way
electromechanical valve and a pneumatic capacitor to minimize the response time for the
changing pressure in the capacitor. These lumped-parameter models represent founda-
tional blocks upon which timing models of pneumatic circuits can be built for a variety of
applications from soft robotics and industrial automation to high-speed microﬂuidics.
[DOI: 10.1115/1.4049009]
1 Introduction and Motivation
In the early days of computing, both ﬂuidics and electronics
showed promise as logic elements for general-purpose digital
computers, including the ﬂuid operated digital automatic com-
puter (FLODAC), constructed from ﬂuid jet-based ampliﬁers in
the 1960s [ 1], and the more famous electrical cousin, the elec-
tronic numerical integrator and computer (ENIAC), constructed of
vacuum tubes in the 1940s. Over the remainder of the 20th cen-
tury, the electrical transistor progressed to power the greatest
advances in modern technology while the ﬂuidic switches largely
disappeared from view. However, in recent decades, microﬂuidic
large-scale integration [2] has shown potential in new ﬂuid control
applications, driving the size of ﬂuidic components smaller and
into increasingly complex circuits. One application area, the ﬁeld
of soft robotics, has found use for ﬂuidic circuits in demonstra-
tions ranging from oscillating octopus arms [ 3] to crawling [ 4]
and rolling [ 5]. These robots exhibit response times in the range
of seconds to tens of seconds and are modeled with linear ﬂuidic
analogies to linear electrical timing models or application-speciﬁc
ﬂuidic timing models. Linear resistance models for duct ﬂow
require several assumptions, including purely viscous losses, fully
developed laminar (low Reynolds number) ﬂow, and incompressi-
ble ﬂuids. Linear capacitance models rely on linear material defor-
mation properties and often neglect important thermodynamic
considerations. A more general timing model for pneumatic com-
ponents should include nonlinear effects due to compressible ﬂu-
ids, the inertial losses from turbulence caused by faster ﬂow and
ﬂow through bending or rough pipes, and the thermodynamic
effects of expansions and contractions. Such a model would allow
improved optimization of component designs and pneumatic cir-
cuits for speed.
In electrical timing models, resistors ( R), inductors ( L), and
capacitors ( C) provide the fundamental passive building blocks
for circuit analysis. Fluidic circuit analogies exist for each of these
three components [6,7], where pressure ( P) is analogous to voltage
(V) and volumetric or mass ﬂow (Q or _m, respectively) is analogous
to current ( i). While inductance plays an important role in the
dynamics of hydraulic systems, exhibited in second-order dynamic
effects like the ringing of a “water hammer,” our focus on pneu-
matic systems allows us to neglect this piece of the timing model
due to the low density of air. This ﬁrst-order dynamics assumption
is validated by signiﬁcant response time testing in this paper.
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

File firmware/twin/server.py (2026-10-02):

"""FlowIO P0 数字孪生服务：pn_twin.dll (真实逻辑层) + 本地 Web UI  [API v1.2]

启动:  python server.py   然后浏览器打开 http://127.0.0.1:8000
依赖:  仅 Python 标准库 + pn_twin.dll（本目录，由 gcc 编译）

v1.2 新增 (S1/S2 孪生平台扩展):
  GET  /api/board/state[?since=s]     板级电气孪生快照 (board_model, 600s 历史)
  GET  /api/board/sim/presets         仿真参数域表 (前端动态表单)
  GET  /api/board/assembly            3D 装配 (meshes/assembly.json)
  GET  /api/board/history/export      历史四通道 CSV 导出
  GET  /lib/*.js /meshes/*.stl        静态资源 (echarts / three.min / OrbitControls / STLLoader)
  GET  / | /webapp/*                  v2 前端 (webapp/ 零构建直服); /classic 旧 gui; /gui→301 /
  POST /api/board/sim                 参数化电路仿真重算 (buck/dior/valve/i2c)
  POST /api/time                      时间控制 (暂停/倍速/单步)
  POST /api/record | /api/record/replay  命令录制与回放
"""
import concurrent.futures
import ctypes
import json
import os
import re
import sys
import threading
import time
from http.server import BaseHTTPRequestHandler, ThreadingHTTPServer
from pathlib import Path

ROOT = Path(__file__).parent
WEBAPP = ROOT / "webapp"                            # v2 前端 (零构建 ES Modules)
PORT = int(os.environ.get("TWIN_PORT", "8000"))

sys.path.insert(0, str(ROOT))
import board_model   # noqa: E402  (S2 板级电气孪生纯模型)
import sim_engine    # noqa: E402  (S1 参数化仿真引擎)

API_VER = "1.2"
BOARD = board_model.BoardModel()
REC = {"on": False, "buf": []}                       # 命令录制 (wall-clock 时间戳)
TIMECTL = {"paused": False, "speed": 1.0, "step_once": False}   # 时间控制
CARRY = 0.0                                          # 分数倍速累加器 (tick_loop 专用)
SIM_POOL = concurrent.futures.ThreadPoolExecutor(1)  # 仿真超时保护 (单工位串行)
_SIM_BUSY = False                                     # 仿真工位忙锁: 防重叠请求在单工位上堆积挂死
REPLAY = {"on": False}                                # 时序回放进行中标志 (防重入 409)
_REPLAY_LOCK = threading.Lock()                       # REPLAY 标志 check-and-set 原子化

lib = ctypes.CDLL(str(ROOT / "pn_twin.dll"))
lib.pn_twin_state.restype = ctypes.c_uint32
lib.pn_twin_sensor.restype = ctypes.c_float
lib.pn_twin_sensor.argtypes = [ctypes.c_uint8]
lib.pn_twin_valve_duty.restype = ctypes.c_uint8
lib.pn_twin_valve_duty.argtypes = [ctypes.c_uint8]
lib.pn_twin_pump_duty.restype = ctypes.c_uint8
lib.pn_twin_cl_status.restype = ctypes.c_int
lib.pn_twin_command.argtypes = [ctypes.c_char_p]
lib.pn_twin_set_sensor.argtypes = [ctypes.c_uint8, ctypes.c_float]
lib.pn_twin_set_leak.argtypes = [ctypes.c_uint8, ctypes.c_float]
lib.pn_twin_leak.restype = ctypes.c_float
lib.pn_twin_leak.argtypes = [ctypes.c_uint8]
lib.pn_twin_port_pressure.restype = ctypes.c_float
lib.pn_twin_port_pressure.argtypes = [ctypes.c_uint8]
# TinyML 泄漏检测导出已随 spec §12 下线（2026-10-02）：pn_twin_leak_detect/pn_twin_ml_samples 原型一并移除

CL_NAMES = {0: "IDLE", 1: "RUNNING", 2: "DONE", 3: "TIMEOUT", 4: "ERR"}


def _board_step(dt):
    """板级电气孪生步进 (duty 为 c_uint8 无符号, >0 即激励)。"""
    BOARD.step(dt, [lib.pn_twin_valve_duty(i) > 0 for i in range(8)],
               lib.pn_twin_pump_duty() > 0)


def tick_loop():
    global CARRY
    while True:
        if TIMECTL["paused"] and not TIMECTL["step_once"]:
            time.sleep(0.05)
            continue
        if TIMECTL["step_once"]:                 # 暂停下单步：执行一次 tick 后清标志
            lib.pn_twin_tick()
            TIMECTL["step_once"] = False
            _board_step(0.05)
        else:
            # 分数倍速累加器: n=本周期 dll tick 数, 可为 0 (speed<1 时隔周期才动)。
            # dll 与板级同进同停 (n tick ↔ 板级 0.05n s), 时间基严格一致;
            # 不再用 round 钳 1 —— 否则 speed<0.5 时 dll 仍 1× 而板级慢速, 两者发散。
            CARRY += TIMECTL["speed"]
            n = int(CARRY)
            CARRY -= n
            if n:
                for _ in range(n):
                    lib.pn_twin_tick()
                _board_step(0.05 * n)
        time.sleep(0.05)


def _replay_run(evs):
    """后台时序回放线程: evs 为 [(t, cmd)] (t=墙钟秒), 按 t 升序相邻注入,
    间隔 sleep min(dt, 0.5s) (上限防录制长间隙把回放卡成半永久)。
    HTTP handler 立即返回不占线程; finally 清 REPLAY 标志放行下一次回放。"""
    try:
        t_prev = None
        for t, cmd in sorted(evs):
            if t_prev is not None:
                time.sleep(min(max(t - t_prev, 0.0), 0.5))
            lib.pn_twin_command(cmd.encode("utf-8"))
            t_prev = t
    finally:
        with _REPLAY_LOCK:
            REPLAY["on"] = False


class Handler(BaseHTTPRequestHandler):
    def _send(self, code, body, ctype, extra_headers=None):
        data = body.encode("utf-8") if isinstance(body, str) else body
        self.send_response(code)
        self.send_header("Content-Type", ctype)
        self.send_header("Content-Length", str(len(data)))
        self.send_header("Cache-Control", "no-cache")
        if extra_headers:                       # v2: 301 重定向等附加头
            for k, v in extra_headers.items():
                self.send_header(k, v)
        self.end_headers()
        self.wfile.write(data)

    def _json(self, obj):
        self._send(200, json.dumps(obj, ensure_ascii=False), "application/json; charset=utf-8")

    def _err(self, code, msg):
        self._send(code, json.dumps({"error": msg}, ensure_ascii=False), "application/json")

    def _query(self, key):
        """从 self.path 提取查询参数值 (无则 None)。"""
        qs = self.path.partition("?")[2]
        for kv in qs.split("&"):
            if kv.startswith(key + "="):
                return kv[len(key) + 1:]
        return None
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

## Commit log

2026-09-21 P0 固件骨架：四层架构 + 主机单元测试 21/21 全绿 + ESP32-S3 目标机编译通过
    - pn_core：类型/HAL契约/动作层(set-open-close三胞胎/组合动作/状态字/节能/超压保护)/非阻塞压力闭环/二进制协议(CRC8+重同步)
    - pn_hal_esp32：LEDC 阀泵 PWM、RMT 舵机驱动 kit 开关、I2C 传感器(XGZP6897D 读数待传感器到货后按 V3.2 手册填充)
    - tests：mock HAL + 21 用例全绿(发现并修复 release 漏关进气阀、协议 resync 丢 s_pos 复位两个真 bug)
    - main：10ms 控制任务 + 串口 CLI
    [actions.c, closedloop.c, hal_esp32.c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]
2026-09-21 固件改进：XGZP6897D 真实 I2C 驱动 + 自检/闭环 CLI + 泵运行护栏 + 硬件映射修正
    - pn_hal_esp32: XGZP6897D 完整驱动(0x30<-0x0A 启动转换/轮询 busy/0x06 读 24bit 有符号/量程系数换算 kPa)
    - pn_hal_esp32: 阀 idx5/6 重映射为 kit 充气/吸气三通阀舵机(带首次上电语义标定提醒),泵=kit 泵舵机开关
    - main: G/X 闭环 CLI 命令、F 硬件自检(传感器/阀咔哒/汇流管 dP)、泵 120s 连续运行安全护栏
    - 目标机 esp32s3 编译通过,主机测试 21/21 保持全绿
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2026-09-21 2D 前端修复：sim() 多余括号导致整段 JS 解析失败(按钮全死)+仪表 dasharray 指针+动态端口标签 id+防缓存头
    [server.py]
2026-09-21 修复数字孪生命令失效：ctypes 需要 bytes 而非 str（str 导致服务端 ArgumentError，命令从未到达 DLL）+ check.js 前端冒烟检查工具（语法/处理函数/id 引用）
    [server.py]
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2026-09-21 twin: 超压锁存可恢复（/api/reset 虚拟断电）+ 错误横幅 + e2e 状态污染修复与覆盖补全
    用户实测踩中：充过 120kPa 触发固件超压硬锁存(bit15 永不清除)，真机语义=断电重启，
    孪生此前无恢复路径。本次：
    - server.py 新增 POST /api/reset（pn_twin_init 等效虚拟断电）
    - gui.html：错误横幅+⟳虚拟断电重启按钮（保留'锁存仅断电可清'的安全语义）
    - twin_api.c：init 时 s_last_cl 归零（重启不残留 DONE）
    - e2e 修复状态污染：Scheduler 停止≠硬件停止→停后立即 S 31；启动先 /api/reset 保证确定性
    - e2e 修复选择器歧义：'text=注入'匹配到 3 个元素点到标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
    [server.py]
2026-09-21 twin: 用户审查反馈修复——端口压力/启用4-5/自说明按钮 + 测试隔离 + 用例文档
    问题1（端口控制）：
    - 根因：卡片压力误绑 S1（孪生不演化该传感器→恒显 0.0）→ 改为'端口压力'=
    阀开跟随汇流管 S0/阀关密封保持（与气球同源），卡片头部加语义说明
    - 端口 4/5 启用（取消备用灰显，P0 七阀全在）；S1 从端口卡片退出，
    归位为右栏'端口侧探头 S1（需注入）'
    - SVG 标注放大重排：压力表标签'汇流管压力'11px、数字 15px、
    端口 12px/阀1-5 10px，去掉被套筒遮挡的'汇流管'小字
    问题2（自说明）：
    - F/T/L/X 四个维护按钮加悬停完整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
    [server.py]
2026-09-21 twin: 物理模型真实化——一阶气动规律取代恒速简化（禁止误导性硬编码）
    审计发现 6 处失真并全部修正：
    - 升压恒速且与 PWM 无关 → dp/dt=K·duty·(1−p/Pmax)，P-Q 一阶渐近死点 65kPa(规格50-70)
    - 泵可充到 130 假上限 → 渐近 65 死点，永不超过真实泵能力
    - 抽气不产生负压 → 对称真空模型，渐近 -45kPa，负压密封自然回充
    - 排气恒速 → 压差驱动指数衰减(τ=1.6s)
    - 微漏恒定值 → 比例漏率(1%/s)
    - 注入不钳位 → 传感器 ±100kPa 量程饱和（真实 XGZP6897D 行为）
    ⚠ 重要发现（固件缺陷，待用户决策）：超压保护阈值 120kPa > 传感器量程 10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
2026-09-22 笔记14: 学术地图与潜在客户清单——引用 FlowIO 的 83 篇论文全量挖掘
    方法：Semantic Scholar 被引 API 全量(83篇, 2021-2026) → 拼音姓氏筛出 42 篇中国作者(51%!)
    → AMiner 逐篇机构核查(10 篇深度+团队交叉确认)
    核心发现：
    - 中国是 FlowIO 最大用户群(过半被引含中国作者)，国产替代的市场判断被数据证实
    - 客户清单：浙大(罗仕鉴/孙凌云/王冠云圈, KiPneu/SnapInflatables/MiuraKit 三篇)、
    清华(未来实验室 MorphingSkin UIST'25 + 医学院蠕动泵压力源 + 机械系 DEA 阀)、
    南科大戴建生团队+深技大+iSoRD、深大、港理工(飞行软爪)
    - 直接竞品规格锚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
2026-09-22 文献库全库整理：统一命名+逐篇内容验证+81篇全文提取+分层阅读笔记
    - 统一命名 YYYY-一作姓[-venue]-slug：根目录 9 篇（含 AlHajri 从 git 历史恢复为
    2022-aljomairi-smarchs-thesis-pneuknit、pumpsources 年份 AMiner 证实 2020）、
    citers 81 篇（75 自动匹配 S2 元数据 + DOI/人工补 6 + 删除 Xavier 重复件）
    - 逐篇验证：pypdf 首页标题 vs S2 元数据，80/81 meta 论文全齐+2 篇用户补充
    （KnitSkin/Castillo）；真缺 2：AirPinch（在清单）+S2 垃圾条目
    - 81 篇全文提取（2 篇数学字符 errors=replace 修复）
    - citers/READING-NOTES.md：A 核心深读 9 篇结论沉淀｜B 竞品规格横表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
    [2023-Morita-InflatableMod-Untethered-and-Reconfigurable-Inflat.txt, 2023-Shtarbanov-SleeveIO-Modular-and-Reconfigurable-Platform-for-M.txt]
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2026-09-22 孪生物理 v2 + TinyML Phase 0 泄漏注入落地（孔口方程+容积耦合+泄漏数据工厂）
    物理 v2（PHYSICS-SPEC 已批准实施）：
    - 孔口流 Q=C·√(P_low·ΔP)（Xavier Eq.5/6 ANSI 形式）取代线性压头
    - 多变气体定律 dP/dt=γ·P/V·Q（γ=1.2）+ 容积耦合 V(n)=V_m+n·V_p
    - 开阀瞬时等温混合、choked flow 钳位
    - 标定锚点：死点 61kPa/真空 -38kPa（Shtarbanov thesis Table 2）
    - PUMP_C=9e-8/VENT_C=1e-5/LEAK_C=1e-5（实验校准，理论推导存在量纲差以实测为准）
    TinyML Phase 0（SPEC 15 决策已批准）：
    - twin_api 新增 pn_twin_set_leak/pn_twin_leak（7 元件独立泄漏系数）
    - 泄漏模型：端口泄漏作用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
    [server.py]
2026-09-22 spec(ml): TinyML 泄漏检测训练管线 SPEC+PLAN（待用户审查）
    SPEC：五阶段管线（数据工厂→特征→训练→评估→导出），
    工况矩阵 2304 场景（8元件×4严重度×4工况×3压力×3端口×2噪声），
    3 分类（normal/minor/major），1D CNN ~10KB int8，
    验收：normal R≥95% / leak_major R≥90% / ≤50KB。
    PLAN：5 个 Task 含完整代码（generate_dataset/prepare_features/
    train_local/evaluate_model/export_edgeimpulse），TDD 步骤+验收清单。
    无硬件依赖——全部在 PC+孪生上完成，到货后仅烧录+校准。
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2026-09-22 战略修订: B2B 唯一主线 + 开发者身份修正 + 求职并行
    核心变更（用户 2026-09-22 确认）：
    - 开发者身份：独立开发者（上海，2年嵌入式+6月AI），非北航博士生
    - 商业模式：B2B 部件供应为唯一主线（切口A），家用整机降为远期
    - 开发节奏：全职→求职后业余（爱人在职+储蓄=可持续）
    - 临床合作：从'第一步'降为'Phase 2（B2B 有收入后）'
    - 求职计划：找嵌入式工作（补充技能+收入），下班后继续 B2B 开发
    修订文件：
    - README.md：重写为 B2B 定位 + 四大核心卖点 + 开发节奏
    - 笔记08：切口A升级为'唯一主线'+四大卖点，切口B降级
    - 笔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
2026-09-22 厂商资料核对修正: PSRAM Quad→Octal@80M(N16R8 R8=八线,sdkconfig+defaults锁定)+接线表对齐固件7通道+引脚黑名单(35/36/37被Octal独占,GPIO48=WS2812)+板卡事实(COM口烧录/出厂AP固件) — idf.py全量编译通过(octal驱动编入,bin 284KB)
    [hal_esp32.c]
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2026-09-22 feat(ml): Stage 3 训练达标——v3工况修正(hold/vacuum密封态,移除泵流淹没信号的inflate/release)+噪声校准[0.2,0.5] → Test acc 94.94%(验收≥90%), TFLite int8 34KB(≤50KB); 诊断发现:泄漏检测有效工作区=密封态
    [ml_dll.py, ml_scenarios.py, ml_train.py]
2026-09-22 feat(ml): Stage 4 评估全过——normal R=100%/major R=91.2%/acc 94.85%(int8推理)/34KB; 重大泄漏零漏报为正常(安全关键); 修复计划稿语法错误
    [ml_evaluate.py]
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2026-09-23 物理v2.1修复端口压力冻结bug(用户报告): 5端口独立气压节点+关阀快照+端口泄漏移至端口侧(阀关对汇流管不可见)+H诊断保压命令+ports_p导出+GUI去前端冻结hack; ML v5连锁: 20Hz诚实采样率(原50Hz虚高2.5倍)+Δ可观测标签+类平衡 → 95.73%/零重大漏报/18KB; 114测试全绿
    [actions.c, cli.c, ml_dll.py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]
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2026-09-23 传感器手册对照修正(XGZP6897D-C V1.1): 驱动三错修复(I2C地址0x58固定非0x6D/直读0x04非0x30启动/K因子2^21非2^24差8倍,到货必炸项)+双传感器必须TCA9548A+上电零点自校准步骤; ML随机化并入零漂残差+种子固定+死区0.25 → 94.5%/normal R 99.4%/major R 96.2%(零漏报)/18KB; idf编译过+114测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
    [hal_esp32.c, ml_dll.py, ml_features.py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]
2026-09-23 TCA9548A模块资料落地: 驱动改通道切换式(0x70拨码默认/写1<<ch选通/传感器#1→CH0#2→CH1/逐通道探测)——修复两只0x58同挂总线冲突(第4号到货必炸项); 装配指南接线表+I2C扫描预期(0x70→选通→0x58)更新; 模块原理图入库; idf编译过+QEMU冒烟7/7
    [hal_esp32.c]
2026-09-23 MOS模块手册对照修正(资源/MOS.pdf 7页逐读): 实为CORE SET四路光耦隔离模块(买2块=8通道)非8路低边——触发方式证实高电平有效PWM(0~20kHz,LEDC 1kHz合规,阀保持降占空比实验合法,'手动控制'系1688分类字段误填); 新灰区=输入下限3.6V>ESP32 3.3V(参数表与属性表自相矛盾)→到货60s连续PWM触发门禁+电平转换预案; 接线拓扑修正:低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
    [hal_esp32.c]
2026-09-23 电磁阀手册对照修正(0520D/F规格书+散件资料,用户到货前最后一批白牌件手册): 真空渐近-58→-53.3(VALVE_P_MIN_KPA,0520D/F动作压力下限-53.3~+300/-53.3~+100kPa,阀是链路最弱环节,泵-58冗余不可用)+VENT_C注释如实化(演示时标假设非实验校准,裸阀Cv0.05/0.10高2量级到货重标)+SEAL_LEAK锚定手册(0.01/s好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
    [hal_esp32.c]
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2026-09-23 TinyML部署进固件+GUI泄漏检测实验室(用户质询'固件可用为何不用模型'触发): components/pn_ml纯C int8推理器(零依赖,host/ESP32/QEMU三端同码,权重6299参数由tflite导出,含zp_in·Σq_w项与per-channel量化的完整TFLite语义) + pn_core leak_detect.c(20Hz环形采样挂两侧tick,CLI 'L'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
    [cli.c, main.c]
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2026-09-23 泄漏实验室UX修复(用户实测反馈2问题): ①检测总normal=工况语义非bug——用户S隔离保压下注入端口泄漏,物理v2.1正确判定'不可见'(A6b语义),但前端无引导→/api/leakdetect加工况守卫hint(端口阀全关+端口泄漏>0时提示改用H保压)+面板加工况前提说明; ②内嵌浏览器原生select无法选择→部位/强度全部chips化(按钮组,webview可靠)+三档强度预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
    [server.py]
2026-09-23 泄漏检测工况感知分级披露(用户设计质询'充/抽/释中能否检测'触发): /api/leakdetect 加 regime(H保压/S密封/充气中/抽气中/释放中/混合)+reliability(high/low/none)——模型按密封态训练,动态工况属分布外:充/抽气仅在死点附近泄漏主导信号(用户实测13:13:23死点充气中检出minor即此例,有效但非保证),释放中排气大流完全淹没泄漏; 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
    [server.py]
2026-09-23 真机首次点亮成功(COM3/N16R8): 三连bug修复——①stdin死路:fgets(stdin)真机收不到(默认console只配输出,QEMU轮询读掩盖)→app_main装UART驱动+uart_vfs_dev_use_driver(QEMU跳过); ②RMT内存级联:mem_block_symbols=64>S3每通道48词→每舵机吃2个TX通道,第3只no free tx cha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
    [hal_esp32.c, main.c]
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2026-10-01 SPEC: FLOWIO-CN P1 升级大脑 PCB 设计规格书 v1.0——待用户审查
    10 章: 产品定位/设计决策8项/系统架构(电源+引脚表+电路块7个)/PCB布局约束6项/层叠4层/BOM约95器件(含LCSC编码)/制造输出/测试计划8项/修正记录8条/风险5项
    关键设计:
    - 电源: 单轨diode-OR(修正自双轨)+TPS54331 Buck 3.3V+CH340N从3.3V取电(消除倒灌)
    - 驱动: AO3400A×8直驱(每路4元件)+WJ500V端子
    - 传感: TCA9548A 5通道+12颗I2C上拉+XH2.54×5
    - 布局: 天线净空≥15mm+TPS54331 PH<5mm+I2C远离开关路径
    - 修正8条: 电源简化/CH340N供电/I2C上拉/strapping/SS8050外围/WS2812B外围/无开关/SS14≠SS34
    基于: 9份IC+外围数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
2026-10-01 feat(P1): freerouting 双轮布线完成 146→17 未连接·零短路; 目视检查抓到并修复天线禁布区丢失
    - baseline 采纳: freerouting v2.4.1 (headless CLI, DSN/SES 回灌) 两轮
    rip-up&reroute + BatchOptimizer; 佐证源码 MazeRipupResolver 的
    fanout 保护/ripup 代价机制 (FANOUT_COST_CONSTANT=20000)
    - 布线后清理: 平面重建 (GND 全实连)、线宽 0.25→0.2 回退消除 130 间距
    违规、zones_intersect/starved_thermal 清零
    - 目视检查 (用户强制要求) 顶/底 2400×2000 渲染逐区检查 + 程序化核实:
    * 发现 route_pcb.py 重建平面时删除了天线禁布区 → GND/+3V3 填充
    铺进 ESP32 天线正下方 (HitTestFilledAre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
    [flowio-p1-round2.dsn, flowio-p1.dsn, flowio-p1.kicad_pcb]
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2026-10-01 fix(pcb): 删坏+5V过孔+D10.1重连; HD(77,62)→(68,65)让出D10走廊 (hole 6→1, dangling 2→1)
    [flowio-p1.kicad_pcb]
2026-10-01 fix(pcb): GND过孔避让C1.1 (修正模型: 矩形焊盘角伸出max/2圆外, 改点对旋转矩形精确距离); clearance 3→2
    [flowio-p1.kicad_pcb]
2026-10-01 feat(pcb): DRC 攻坚 17→6 未连接·其余 error 类全零 (freerouting 三轮+自研 boardgeom/netdoctor 全障碍路由)
    - boardgeom: 点对旋转矩形精确距离/分层走线校验/过孔孔距规则/禁布区+板边建模
    - netdoctor: 填充岛探测(PIP)/岛间跳线/焊盘逃逸/In1-In2-B.Cu 多层 BFS 路由
    - 修复: 天线禁布区找回·HD移位·D10/C16/C15/C3/U3.2 电源锚·U2/U5 GND 逃逸
    (U5.2 via-in-pad)·J2.CC 走线绕行·TP8 微移·R13/R14/R29 strap 供电·GND 碎片缝合
    - 遗留 6 未连接需 GUI 收尾: R13 簇/R29 簇/C3-U3.2 簇×2/GND zone 对/3V3 zone 对
    [flowio-p1-round3.dsn, flowio-p1.kicad_pcb]
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2026-10-01 security+docs: 自研脚本高危清零 (Mimosa); aminer/github MCP 复查与 KRT 能力回填
    - gen_pcb: exec(源码切片)→ast 受限解释器 (135 PARTS 等价, For/f-string/算术白名单节点)
    - fix_islands: eval(argv)→ast.literal_eval
    - 写文件统一 pathlib write_bytes (字面量/受控路径, LF 精确); gen_sch 系删除 OUT 上跳推导
    - 仿真输出迁 tools/sim/out (同目录); simlib 不落盘由 run_all 字面量写
    - 第三方参考源码移出项目树 → E:/FLOWIO-外部参考/_ref (1034 高危处置)
    - spec/plan: aminer SSE 端点实测 200/token 有效至 10-21 (需重启会话加载);
    github 插件=skills 设计如此; KRT --rip-existing-nets/--ripup-blocker-s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
2026-10-01 feat(pcb): T1 KRT repair_planes 全层修复 → 未连接 6→0, error 类全零!
    - GND F/B/In1 + 3V3(12区11路)/5V(6区5路) In2 平面断区全接
    - oracle_reconnect 连带解决 R13/R14/C3-U3.2 口袋簇 (6→0 超预期)
    - 剩余仅外观类: silk_over_copper 54 + courtyard 44+13 (豁免清单)
    - 环境补装 scipy/shapely + rust grid_router v0.22 + kicad_oracle v10 上游bug补丁
    - 附注: min_hole_clearance 25→20 (JLC 经济档合规) + 8处 via-in-pad 需 IPC-4761 Type VII
    [flowio-p1.kicad_pcb]
2026-10-01 feat(fab): 终版打样包 (未连接0/error类0) + 工艺注意事项 (via-in-pad Type VII ×8, hole clr 0.20)
    三重验证: KiCad DRC + KRT check_connected (75网全通, refill交叉核对) + 禁布区探测0命中
    目视检查: 顶/底渲染, 视觉疑点经程序化裁决为GND填充纹理误读
    [flowio-p1-B_Cu.gbl, flowio-p1-Edge_Cuts.gm1, flowio-p1-F_Cu.gtl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]
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2026-10-02 fix(twin): board_model 关断续流物理修正 (τ=L/R_coil, 与 sim_engine 同源)
    [board_model.py]
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2026-10-02 fix(fw): tca I2C 超时单位修正 (ms 字面量)
    [hal_esp32.c]
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2026-10-02 feat: P1 板级孪生五支柱交付 (S1-S5) API v1.2——终验+双源漂移修正+HANDOFF
    [board_model.py]
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2026-10-02 fix(fw): F1 泄漏检测从 pn_core 彻底解耦 (cli L=off/删leak_detect/断pn_ml依赖) → virtual 复活
    [cli.c, server.py]
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2026-10-02 fix(twin): F4 Minor 清偿——loss_mw 动态化(同源sim_engine)/SIM忙锁503防挂死/replay时序后台线程+409防重入/冒烟覆盖+4
    [board_model.py, server.py]
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2026-10-03 feat(site): GitHub Pages 静态演示站 + fix: make_bom/consistency_test 改 Path.write_bytes 清路径穿越高危
    [case_bottom.stl, case_top.stl, parts_b.stl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]
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2026-10-03 fix(site): 3D 场景三层修复 — 动态 import 改写 + vendor/addons 整树拷贝 + importmap 裸值；验收升级为场景注册+像素探测
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2026-10-03 fix(CAD): 装配逻辑统一 + CAD 测试体系 (L1-L4)
    根因 (spec: 2026-10-03-cad-assembly-truth):
    - 四个生成源 z 基准互相矛盾: 板趴腔底(2.4) vs 板坐铜柱(7.4) 各执一词
    - 顶盖被建模成带底板方盒 (case_top 99% 三角形在 z<5), 与下壳全面穿插
    - make_assembly 矩阵平移放在第4行 (FreeCAD 约定第4列) -> PCB 从未真正落位
    - 外壳 19mm 装不下真实端子 (WJ500V 模型实测 17.5mm 高)
    修复:
    - case_geom.py 单一真相源: 装配栈/槽位/器件尺寸/爆炸契约, 四个生成源统一引用
    - 装配栈定稿: 板坐铜柱顶 z=7.4, 器件基面 9.0, 内腔顶 27.1, 总高 29.5
    - 顶盖重构: 裙边舌环(2.8..4.8 内缩 0.4 间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
    [case-bottom.step, case-bottom.stl, case-top.step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]
2026-10-03 site: CAD 装配修复产物 — 4 部件装配清单/29.5 总高/真实顶盖+铜柱栈位/角部 relief; 移除空 parts_b
    [case_bottom.stl, case_top.stl, parts_b.stl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]
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2026-10-03 docs(校准): spec/plan 与实况对齐——连接器 15→17(枚举本为2+4+3+8)、BOM 33→38 行(实测)、槽位双射 17↔17(9侧槽+8端子槽, relief 不计槽)、T2 环境标注已完成、aminer 风险表述按 v2 修正
2026-10-03 feat(T1-T4): 器件几何层落地 — devices.json(33C号/123位号/17连接器定锚) + device_geom(OBB/端口射线/FCL管理) + 网表解析(101网/7503电气边) + device_graph(17↔17完美匹配45.14mm/flows零违例/负测试) + drl(278孔/NPTH4) + L5 13断言全绿; 真实发现3项入known-is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
2026-10-04 docs(3.7V两轮修正): 用户查证listing确有3.7V SKU,推翻'目录最低4.5V'旧论断 + 修正物理论证(共轨PWM轨道电流由功率决定2W→400mA@5V,与线圈档无关,'+22%电流'仅直驱成立) — 裁定: P1.1主BOM维持4.5V(参数有据+占空比浅+轨匹配) + 采购单加3.7V样品×2(F0520D-3.7V/ZR370-03PM-3.7V,30V/10A电源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
2026-10-04 fix(T1): 评审 should-fix x3 — 段残缺早退防假绿/崩溃; 包络 FAIL 详情挂 ebad 修正误导; 余量公式去重(_pneu_envelope_bad 返回 (bad,min_margin) + _pneu_tag 复用)
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2026-10-04 chore(T2): 网表+ERC 再生成 — ERC 0 error / 50 可解释 warning
    - erc.rpt: Errors 0; warning 构成 = 14 自建符号+footprint 未入库(T3 建)
    + 13 TestPoint + 8 电源符号 mismatch + 1 PH (后两类为基线原有)
    - net.net / fab/flowio-p1.net: refs 135→160 (D1 移除, +R55-64/Q13-16/D12-15/
    J20-23/U6/U7/C18/TP13), nets 101→119
    - 黄金值(推导): netlist.py elec_edges 8778→12403 — 解析器逐段吞段为既有行为
    (KiCad10 多行 net 块致 split 失配, 基线亦然), 数值仅作粗粒度监控;
    device_graph: nodes 123 不变(pos.csv 未动), elec_edges 7503→7381(D1 消失),
    17↔17 匹配 True; flows 违例 0→2 = 陈旧 vin_dc 流引用已删 D1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
2026-10-04 fix(T2 收尾): flows.json 电源流 DC005→USB-C + P1.1 泵/S/V/F 流新增 — 交叉校验归零
    - make_flows.py (源头) + flows.json/hotspots.json (生成物):
    - vin_dc(J1,D1,C1, 已删 DC005/D1) → vin_pwr(J1,C17,C1): USB-C 电源口
    直挂 +5V 语义; vin_usb(J2,D2,C17 调试口或门) 保留 — 电气拓扑均真
    - 新增 elec: gateS/gateV/gateF (U1→R55/56/57→Q13/14/15→J20/21/22) 与
    pump (U1→R58→Q16→J23) — 相邻对全为非电源网真实电气边
    (IO15-18/GATE_x/DRV_x); gateS/V/F live=valves[8..10].i_A (固件 N_VALVES
    扩展后点亮, 现 0 底光无害), pump live=rail_5v.load_a (泵为 5V 主负载的
    现行遥测代理)
    - 新增 air: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
2026-10-04 chore(评审 should-fix x5): 注释真值化/守卫补齐/LCSC 待补集中化/自建符号防遮蔽断言
    1. make_flows docstring 'z = WALL + PCB_T = 4.0' → 引 case_geom 真值
    (Z_BOARD + PCB_T, 现 9.0); test_flows 断言消息 'z 应为板面 4.0' →
    动态引 Z_TOP (失败消息不再误导)
    2. test_flows 裸 main() 补 __main__ 守卫 (4830658 描述声称加了但只加在
    make_flows — 补齐)
    3. gen_sch: 集中常量 LCSC_XH2P = "" # TODO(T3) 供 J10-J17+J20-J23 引用,
    注释写明 BOM 影响 (12 插座 + U6 共 13 个物料编码待补, 回填后 make_bom
    重跑恢复); U6 处另加 TODO(T3) 行注释
    4. _mk_custom: LIBS[name] 赋值前 assert name not in LIBS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
2026-10-04 feat(T3b): PCB 重布局 100x80 + 五缺陷修复 + 26 新件 — DRC error 归零
    布局 (spec T3):
    - 板框 90x75 -> 100x80: 底边 J10-J17 阀带 (11mm 节距) + 右边 J20-J23 主阀/泵带
    + 传感带重排 (J5 底右角/J6 左壁/J7 顶右角, 为右边缘主阀带让位)
    - 新增 PLACE: J20-J23 + R55-64/Q13-16/D12-15 右侧驱动列 (与 Q3-Q10 同域) +
    U6 XGZP6897D (44,22, LOCAL 内联手建封装: 排距7.96/节距2.54/焊盘0.9x2.0) +
    C18 + U7/R63/R64 (J1 USB-C CC 防护) + TP13 (DRV_PUMP)
    - 安装孔: HA(3.4,3.4)/HC(83,12)/HB(3,28)/HD(73.5,55.7) — HD 避 J15/J16+D9 双冲突
    五缺陷修复 (spec §1):
    1. C9 移 (63,55) 出 J9 XH 壳体投影 (原 43,9)
    2. R3 移 (21,34)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
    [flowio-p1-bom-jlc.csv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]
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2026-10-04 fix(T3 评审): test_flows 出线断言随双带语义真值化 + 注释 3 处纠偏
    阻塞项: test_flows.py:81 仍写死底壁公式 (12 条 air 终点 y=端子y-25), 而
    make_flows._outward_dir 已按 rot 分向 (J20-J23 走右壁 +X) → port9-12 必红。
    修法: 断言改为 end/ctrl = start + dir×AIR_LEN/AIR_CTRL (复用 make_flows.
    _outward_dir 推导, x/y 双向同检, 终点与控制点双验); docstring 中已删除的
    POS_P11 过渡表引用一并真值化。修到 'flows tests OK'。
    注释真值化:
    - gen_pcb PLACE 头注: HD (75,55.9)→(73.5,55.7); 'Q-D 列距 ±3.5'→底带实际
    Q=x-3.0/D=x+2.5 (右带 Q=86/D=81); 'J5→右壁'→底右角(94.5,74)
    - test_assembly L1 p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
2026-10-04 fix(T3 质评): Should-fix x7 — 注释真值化/过孔真裕量/LOCAL 分发防静默/f 带向不变量
    1-3. case_geom 旧值注释: Z_CEIL 23.67→19.1 / SKIRT_Z0 16.67→12.1 /
    BBOX_MM [95.8,80.8,26.07]→现值 [105.8,85.8,21.5] (注明派生自 OW/OH/OUTER_H)
    4. make_flows: docstring TY=68.5→74.0; flows.json meta.air_frame 补双带语义
    (J10-J17 底带 +Y / J20-J23 右带 +X, 方向按 rot 推导) — flows.json 重出
    5. route_pcb: npth_min 3.5→3.7 (净空=3.7-3.15-0.35=0.2 真裕量; 3.5 仅相切
    0 裕量, 原注释'≥0.2'与算术不符) — 选改常量更安全
    6. gen_pcb: LOCAL: 前缀改按封装名注册表分发 (_LOCAL_FP_BUILDERS, 未登记名
    直接 Va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
2026-10-04 fix(T4a): route_pcb SWIG 真相化 — zone getter 撒谎两处 + NPTH 障碍
    - ZONE.GetLayerName()/GetIsRuleArea() 在 KiCad 10 python 撒谎 (新建 zone
    GetLayer()=4 正确而 GetLayerName() 报 F.Cu; 载入含填充板 GetIsRuleArea
    全真→幂等判空失效→zone 翻倍): 幂等判据改 zone COUNT, 逻辑不再依赖
    这两个 getter; 文件级验证 zone 层分配一直正确
    - netcode 预缓存: board.Remove 系操作后 FindNet 返回坏 SwigPyObject
    - pad_exit/pad_pos: FindPadByName 不存在→FindPadByNumber (原 try/except
    静默吞掉, 逃逸候选从未生效)
    - seg_pad_clear: no-net 焊盘不再跳过 (M3 孔=NPTH 障碍, 压孔=短路)
    - 阶段2/3 贪心 L 布线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
2026-10-04 feat(T4b): stage2/3 障碍模型真值化+同位铜去重 — DRC 0 错 (183→172 未连)
    - zone 幂等守卫真正跳过 (只 print 不跳会让累积重跑重建 9 平面 → 10x zones_intersect)
    - 焊盘障碍: 外接圆改朝向矩形半边长; 自定义 pad (J2.7 屏蔽腿 x4) GetSize 撒谎
    0.01x0.01 → 回落 GetBoundingBox 真值 1.9x1.1 (CC1 穿屏蔽腿 shorting 根因)
    - 走线间距: 中心线 0.5 采 3 点 → 宽度感知 (新半宽+既有半宽+0.25) 双向密采
    0.3mm + 过孔入障 (LED_TX_K 距 0.8mm +3V3 逃逸线 0.073 间距根因)
    - seg_ok 板界检查 [0.55,99.45]x[0.55,79.45] (J1 逃逸拐角曾布到 x=100.45 板外)
    - 饥饿热焊盘第二批: R59/Q15/R23/Q16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
    [flowio-p1.kicad_pcb]
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2026-10-04 fix(SOP期A盲测): 6真实卡点修补 — cwd基准统一注(worktree根+tools实际位于hardware/flowio-p1/tools) + L5两档语义澄清(默认schema15/all档13) + pneumatic负压域约束关键断言内联(负压阀仅vacuum_master组/rated_v=4.5/泵包络阀/refs唯一) + DSN-SES封装定位/基线json路径/s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
2026-10-04 fix(T4h-a): GND zone-zone 3条缝合 — 未连4→1, DRC持平142w/0e
    - fragment级union-find定位3孤立zone组件 (57主+3小)
    - 缝合via 0.3/0.6: (70.707,26.726)/(74.325,15.037)/(74.350,23.651) 各F碎片<->B主平面
    - 剩余: IO21 东西轨 1条
    [flowio-p1.kicad_pcb]
2026-10-04 fix(T4h-b): IO21 东西轨贯通 — 未连1→0, DRC持平142w/0e
    - 战术: 弃 In1 硬穿(SE堡垒/IO11墙/BTN_USER阵 30+路径全败) 改 In2 微桥
    - via1(46.2,55.5) 落A-竖线 + via2(62.8,51.4) 落B-竖线x62.8 + In2对角16.6mm
    - 预检全障碍最差净距0.332(规则0.2) 远优于前置代理2µm级近失
    - In2 仅7条走线全在板西北角, 桥刻+3V3大平面(30-79,20-58) 0.65x16.6缺口
    - 诊断链: fix4_io21_analyze/corridor/col/west/rules/route_scan 扫描脚本
    [flowio-p1.kicad_pcb]
2026-10-04 chore(T4h-final): DRC 快照刷新至 4→0 终态 — 未连 0/错误 0/警告 142 持平零增
    - drc.rpt/drc.json 重生成: 0 unconnected, 0 error, 142 warning (类型分布与基线逐项一致, delta NONE)
    - 布线后钻孔回归: +3V3/+5V In2 平面轮廓 6/7 不变无分裂, GND 三层单组件
    - 四套测试绿: assembly 29/0, device_geom 15/0+13/0(all), flows OK, device_graph 21<->21/违例0
    - fix4_status.py 入库 (ratsnest/zone 状态检查可重放)
2026-10-04 fix(T4i-a): fix4_io21 补幂等重放守卫 + docstring 改南线终态 — 消除重跑 double-via 静默累积
    - 落孔前加 _via_exists 式守卫(模式同 route_pcb.py:67): via1/via2 已在板则
    [SKIP] no-op exit 0, 不触碰板文件; 候选搜索对同网增量不敏感(同网不算障碍),
    重跑必复选同一 (46.2,55.5)/(62.8,51.4) 组合, 守卫必命中 — 对齐 fix4_gnd_stitch
    自限结构 (质量审 Should-fix #1)
    - docstring 由已废弃北方案 (via 46.0,40.7/47.3,33.0) 改为已实现南线终态
    (via1 46.2,55.5 / via2 62.8,51.4 / In2 对角), 并补拓扑死局存档:
    In1 硬穿 SE堡垒/IO11墙/BTN_USER阵 30+ 路径全败 → In2 微桥 最差净距 0.332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
2026-10-04 refactor(T4i-b): route_pcb SWIG 措辞对齐实测 + 清扫 TRACK_PRIO 死机制 — 质量审 Should-fix #3/#4
    - :349-352 注释修正: '本进程不做任何 board.Remove' → 'board.Remove 分型:
    zone Remove 必毒化 SWIG 堆; track Remove 实测可用 (:1541 删/:1797 再遍历
    GetTracks 主路径在用); stage4/6 保守全禁'
    - 删 TRACK_PRIO (只写不读) + 永不入板哑 track t (构造后丢弃, 无 Start/End) +
    随之作废的 prio 形参 (唯一传参点 :1780 同步); 调用方无人消费返回值
2026-10-04 refactor(T4i-c): fix 系脚本死代码清扫 — 质量审 Should-fix #4
    - fix3_gnd.py:98 删 if False else 死分支 (引用未定义 ty, 永不走) — 与
    fix4_gnd_stitch/fix4_io21 中同源 pt_seg 干净版对齐
    - fix3_gnd.py:9 / fix4_gnd_stitch.py:10 删未用常量 B_/I1 (保留在用的 F,
    注明 KiCad10 层号非连续)
    - fix4_status.py:17 删 or True 调试残迹 (恢复仅列未连边语义)
    - fix4_io21_analyze.py:9 删猜测残迹 dict LN (下方 ln() 自带正确映射)
    - 验证: 6 脚本 py_compile 全绿; 只读的 fix4_status/fix4_io21_analyze 以
    KiCad python 实跑 exit 0 (板未连 0, 无行为变化)
2026-10-04 feat(T4i-d): 新增 check_route 连通性守门 + 挂入重放链尾 — 质量审 Should-fix #5
    - tools/check_route.py (~40 行, 只读永不落盘): LoadBoard→BuildConnectivity→
    断言 GetUnconnectedCount==0 (打印计数) + 复用 del_bad_via.py --report 铜柱环
    检查逻辑 (PD=2.8/BOSS_RING=1.75/ST 四心) → 双绿 exit 0 / 任一红 exit 1;
    KiCad10 SWIG 无可迭代 GetRatsnest, 明细诊断指回 fix4_status.py
    - rebuild-matrix.json: place_layout 与 gen_pcb_footprint_rules 两条 rerun 链尾
    各挂一步; SKILL.md §2 对应两行同步; 用户级 skill 已重新部署 (deploy_sop_skill.py)
    - 实测: unconnected 0 / boss-ring 0 / CHECK_ROUTE PASS exit 0
2026-10-04 fix(T5a): hole_to_hole 重叠孔去重 15 处 — DRC 142→127w/0e, check_route 双绿保持
    - fix5_dedup_vias.py: 线段+宽度模型判定冗余孔 (铜径向区间 vs 环带交叠, 钻 void
    碎轨豁免), 15 对 wall<0.10 全部可删; 删孔中心终止端点吸附保留孔中心 (16 端点)
    - 背景: 14 对物理重叠孔 (wall -0.062~-0.297, freerouting/stitch 撞孔伪影) +
    1 对 wall=0.064, 均超 JLC 0.25mm 孔距限值且重叠孔会被钻孔 DFM 拒收
    - 去重后全板重填 zone (12 区), Gerber 铜与几何一致
    - scan_fab.py: 制造前工艺扫描 (via-in-pad 13 / hole-to-hole 壁距 / 最小线宽 0.2 /
    设计规则真值 clearance 0.2, hole 0.25, h2h 0.25, cu-edge 0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
    [flowio-p1.kicad_pcb]
2026-10-04 feat(T5b): fab 全套重出 (布线终态+层栈补全) — Gerber 首次真达 ×11 + zip 13 文件
    - fix5_add_layers.py: 板层栈补 Mask/SilkS/Paste 六行 (gen_pcb 最小层栈遗留,
    kicad-cli -l 按层栈表匹配致技术层 Gerber 从未导出; 铜层行必须先于 user 行 —
    排序插入即解析失败, 追加块尾即过, 已实测固化进脚本)
    - Gerber ×14 (11 JLC 集 + 双 Courtyard + Margin) + gbrjob (4 层/100.1x80.1/1.6)
    - 钻孔: drl 450 孔 (416 过孔 232xØ0.3+184xØ0.35, 28xØ0.9 PTH, 6 NPTH=4xM3+2xØ0.6)
    + PTH/NPTH 分体 + drl_map; L5 T4 钻孔避让对新 drl 全绿 (13/0)
    - pos 重出 (vs T3 仅 1e-6mm 浮点尾差, PLACE 未动); BOM 重出 (39 行: SMT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
    [flowio-p1-B_Courtyard.gbr, flowio-p1-B_Cu.gbl, flowio-p1-B_Mask.gbs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]
2026-10-04 fix(T5c): netlist.py 逐 (net) 节点 s-expr 切块解析 — 修复 KiCad10 多行网表错位 (T2 遗留)
    - 旧版行分割按 '\n\t(net ' 找块界, KiCad10 实际为 '\n\t\t(net\n' 多行缩进 →
    永远找不到界 → 每网的 refs 并入其后全部 node (后缀累积), elec_edges 虚高
    12403; 新版逐节点括号深度切块 (net 块 119/119, node 446/446 与文件精确一致)
    - 真值: nets=119 (power 5) refs=160, elec_edges 12403→230 (剔电源后真实共网对)
    - 连带: flows_crosscheck 边集改取全部共网对 (电源网在内) — flows 电源段
    (vin_pwr/vin_usb/buck_in) 相邻对共 +5V/GND/USB_VBUS 属合法拓扑, 旧 0 违例
    是错位解析的虚静默,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
    [bom.csv, flowio-p1-bom.csv]
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2026-10-04 chore(sop): check_fab 22 断言门挂入 rebuild-matrix fab 重出行 — T5 质量审 Should-fix
    - rebuild-matrix.json place_layout / gen_pcb_footprint_rules 两行链尾追加
    'fab 重出 (README-fab 再生命令全链) → check_fab 22 断言门 (exit 0)'，
    sync 面补 README-fab 钻孔谱/线宽谱黄金值 + check_fab 黄金计数 (450 圆孔/148 pos 行)。
    - SKILL.md §2 人读表同步同两行 (机读源与人读表保持一致)。
    - check_fab.py 头注释补挂链声明 (对齐 check_route.py 链尾注明文化)。
    背景: 016a118 fab 全套重出后 check_fab 从未挂入矩阵——fab 包与板漂移无闸门，
    README-fab L87 的 '任何 fab 重出后必须全绿' 仅是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
2026-10-04 fix(T6-0): L4 顶盖干涉 0.2945mm^3 真值修复 — J2 TYPE-C 关键词碰撞
    根因: dims_for 首匹配按 devices 列表序, J2(pkg=TYPE-C-SMD_TYPE-C-6P_1) 误命中
    J1 条目泛关键词 'TYPE-C' (C165948 按 lcsc 序在前), 盒尺寸 8.94x7.35x3.26 顶到
    z=12.26, 探入裙环带 y[4.43..4.8]xz[12.1..12.26] 与顶盖裙边交叠 0.2945mm^3
    (诊断: 逐器件布尔, J2 唯一来源; 其余 10 器件裙带交叠均被侧槽切除).
    修复 (真值修正, 非噪声豁免):
    - devices.json C456012 (J2 本体) 增专有关键词 TYPE-C-6P;
    - case_geom/device_geom 关键词匹配改最长优先 (最具体者胜), J1->TYPE-C-31-M-12
    J2->TYPE-C-6P 各归各位; 全 BOM 对拍: 连接器映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
2026-10-04 fix(T6-QA): 质量审 4 nit + 新探针/断言抓获 3 真缺陷 (气口盲皮×2 + 爆炸层交叠) — 装配链崩溃连带修复, 全家桶绿
    4 nit (规格审遗留):
    - make_case: 13 气口阵列孔 + CEIL_SENS 盖孔补贯通探针断言 (逐孔'孔内无材料/
    孔侧有壁材', 参照 make_manifold §3 模式);
    - case_geom: CEIL_SENS 注释修正 (圆心距最近栅孔角 (46.9,28.9) 2.48 -> 孔缘余
    0.78mm 保证不并孔; 旧'孔带 46.8..50.2'表述易误导);
    - case_geom: PORT_D_F ⌀4.8 补来源注释 (VF/F0520D 排大气口通径真值 ⌀3.0,
    无接管密封要求 -> 经验裕量取通道孔 ⌀3.4 大一级, 非真值推导);
    - test_assembly L3: 爆炸态分离断言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
    [brackets.step, case-bottom.step, case-bottom.stl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]
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2026-10-05 feat(flowio) M0-1/4: 包骨架 + core 抽象层 errors/interfaces — TDD 红绿
    - pyproject.toml (仓库根): pip install -e . 可装; M0 仅 core 子包, stdlib-only
    - flowio/core/errors.py: FlowioError(RuntimeError) 公共根 + Truth/Geom/Route/Sim 四域异常
    (全系继承 RuntimeError, 既有捕获语义不破坏)
    - flowio/core/interfaces.py: 纯 ABC 零域知识 — IActuator(current/effective_v/ref 属性)
    + ISensor(read->Sample dict, protocol 注入位) + BaseModel(params/step/reset);
    多态锚点注释 (spec v2.1 §3.4 三处 if-else 消灭入口)
    - flowio/__init__.py: 公共 API 导出 (errors + interfaces; TruthSource M0-2 追加)
    - flowio/tests/test_core.py: 层次/ABC 不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
2026-10-05 fix(geom) M1-R2 (E②): case_geom 补 pathlib 导入 + devices.json 经包定位指 enclosure 单源 — 电子 3 键真值恢复
    - 预存在缺陷 (评审证伪'兜底等价'): _load_device_dims/_load_pneu 引用未导入的 Path,
    NameError 被宽 except 吞 → 加载恒走内置兜底; 兜底对电子 3 键不等价 ——
    L1(IND-SMD)/LED1(5050)/U3(SOIC) 在兜底表无关键词退化 DEFAULT_DIM, 气动 14 键等价
    - 落位裁定: 不拷贝 —— _DEVICES_JSON 经包定位指 enclosure/ 原位 (与 TruthSource 默认
    路径同一文件); 拷贝至 flowio/geom/ 即第二真值, 无 CI 守门必分叉。兜底表保留 (仓库外降级)
    - 验证: TALLEST 9.5/Z_CEIL 19.1/OUTER_H 21.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
    [parts_f.stl]
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2026-10-05 fix(twin) M2-R: ① 报告同源 — IActuator.duty 报告钩子落地, electrical._solve 报告字段 duty/eff_v 改取执行器侧 (与 i_a 同源; 内置型号两源恒等, 12 场景逐值不动, stub 断言更新) + ② sim_engine 导入注释措辞更正: 惰性导入 → 模块级导入 (board 不反向依赖)
    [sim_engine.py]
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

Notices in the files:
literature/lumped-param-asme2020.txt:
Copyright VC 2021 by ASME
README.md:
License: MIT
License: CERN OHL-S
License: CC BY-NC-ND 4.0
